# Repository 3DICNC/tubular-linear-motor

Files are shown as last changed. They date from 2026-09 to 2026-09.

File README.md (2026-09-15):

# Tubular linear motor

This repository documents an experimental moving-coil tubular motor for a 3D printer. The **active build** is the nine-coil prototype below. Rev62 and Rev64 assets are preserved as recovered historical material; they are not current drawings, calculations, winding instructions, or simulation results.

> **Build status — not qualified.** The active geometry has not yet passed a physical coil, force, thermal, encoder-field, or long-stroke test. The old Rev64 GIF and Elmer images are archived because their coil geometry and/or field representation are wrong. Do not use them to make engineering decisions.

Current nine-coil motor layout — schematic only

## Active prototype — one X-axis rail

| Feature | Current definition |
|---|---|
| Usable coil-centre travel | 370 mm |
| Magnet rod | 39 sections, 466 mm active stack |
| Each section | Two Ø10 × 5 mm axially magnetised N42SH discs, joined N-to-S |
| Spacer | Ø10 × Ø8 × 2 mm low-carbon-steel washer between sections |
| Section pitch | 12 mm |
| Tube | Carbon fibre Ø12 OD × Ø11 ID; buy 500 mm and trim after retention proof |
| Moving coil pack | **9 independent air coils**, 69 mm overall length |
| Each coil | 13 mm bore × 5 mm width, 120 turns AWG25 |
| Wire | 0.455 mm bare / about 0.496 mm finished; prepare 7.5 m per coil |
| Phase order | A–B–C–A–B–C–A–B–C; three series coils per phase |
| Controller | One MKS XDrive 3.6 channel at 48 V; braking resistor required |
| Feedback | RLS RLC2HD / MS05, mounted on the rail side away from the motor field |

The schematic shows intended physical arrangement only. It is not a field plot, animation, force prediction, wiring diagram, or manufacturing drawing.

## Current build documents

1. [Current prototype definition](docs/11-current-build.md) — mechanical, coil, thermal and encoder decisions.
2. [One-rail BOM](docs/12-one-rail-bom.md) — purchase/build list for the 370 mm X rail.
3. [Current winding recipe](winding-machine/docs/CURRENT_120T_AWG25_RECIPE.md) — setup and trial measurements.
4. [Current build records](records/README.md) — winding, force, thermal and release records.
5. [Project audit and withdrawn simulations](docs/13-project-audit.md) — what is historical and why.

## Historical recovered material

- [Rev62/Rev64 history](docs/02-history.md), preserved for provenance.
- [Archived CAD](cad/) and [archived FEMM work](simulation/rev64/), which do **not** match the active nine-coil rail.
- [Legacy manual](docs/ENGINEERING_MANUAL.md), which is a frozen Rev64 reference only.
- [Archived visual material](media/README.md), which must not be treated as a simulation.

## Recalculate and check the archived Rev64 references

These commands validate the recovered historical files only; they do not validate the active prototype:

```sh
python tools/calculate.py
python tools/verify.py
python -m unittest discover -s tests -v
```

## Repository layout

```text
bom/                     Current one-rail BOM plus preserved Rev64 BOM
cad/, simulation/rev64/  Historical recovered files; not the active design
concepts/                Exploratory work; check its status before reuse
docs/11-current-build.md Active mechanical/electrical definition
docs/12-one-rail-bom.md  Active X-rail procurement/build list
media/                   Current schematic and withdrawn legacy visuals
records/                 Current prototype test templates
winding-machine/         Winder hardware plus active winding recipe
tools/, tests/           Archived Rev64 reproducibility tools
```

No license has been selected. Keep the project private until ownership and release choices are settled.

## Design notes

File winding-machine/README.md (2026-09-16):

# Automatic coil winder — active build

This folder holds the hardware work for the coil winder. The **active plan** is a two-stepper machine for the current tubular-motor coils:

- one NEMA17 and driver turn the removable winding mandrel;
- one NEMA17 and driver move the wire guide on the **2 mm-pitch threaded rod**;
- the MKS controller and existing software provide spindle speed, turn count and guide synchronisation;
- no servo, belt reduction, bevel gear, mechanical reversing gear or electrical control design is required for this build.

## What the winder must produce

The target is one independent air coil with a 13 mm bore, 5 mm axial winding width, 120 turns of AWG25 copper (0.455 mm bare, about 0.496 mm finished). The motor uses nine matched coils per rail.

Use [the active winding recipe](docs/CURRENT_120T_AWG25_RECIPE.md) and [the trial record](../records/winding-trial.md). Wind one slow test coil first; its measured dimensions determine the final guide pitch and the design of the motor coil carrier.

## Hardware still required

1. Rigid base, spindle bearings, 13 mm removable mandrel and a simple non-magnetic end stop.
2. Wire-guide carriage driven by the 2 mm-pitch rod, with adjustable tensioner and smooth ceramic/metal eyelet.
3. Two NEMA17 motors, drivers and MKS control board already available to you.
4. Guard around rotating components, accessible emergency stop and a wire-break stop before normal operation.

## Historical files

The `rev_b_gt2`, `rev_c_printed_gears`, older CAD, old BOM and mechanical-reduction documents are retained as concept history. Their original Rev64 coil assumptions were 80 turns of 0.250 mm wire and must not be used for the active winding recipe. `legacy_rev64_winding_parameters.json` preserves those old values.

No current STEP manufacturing assembly is released yet because the spindle/mandrel dimensions need the first physical 13 mm coil trial. The existing hardware concepts can be adapted after that measurement.

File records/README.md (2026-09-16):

# Current prototype build records

These records apply to the active nine-coil prototype. Use the current 120-turn AWG25 definition, not the older Rev64 templates or archived simulation gradients.

- [Winding trial](winding-trial.md)
- [Static force test](force-test.md)
- [Thermal test](thermal-test.md)
- [Prototype release](release.md)

The historical Excel workbook remains in the archive for provenance. It is not an active specification.

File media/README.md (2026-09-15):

# Current nine-coil layout

`current-nine-coil-layout.svg` is a dimensional **schematic**, not a finite-element field plot or an animation. It depicts the active 39-section, 466 mm magnet rod, 12 mm pitch, nine 5 mm coils at 8 mm centres and the rail-side RLS encoder.

## Withdrawn visual material

- `rev64_real_life_motion.gif` and `rev64_animation_preview.png` show the recovered Rev64 six-coil concept at a 40 mm stroke. They are historical visuals only and do not represent the current motor.
- `elmer_coil_motion_study.gif` and its rendered frames are withdrawn from engineering use. The Elmer geometry did not represent the annular coil pack or its field correctly.

These files remain in the repository for traceability. Do not use them to estimate force, flux, movement, fit, or thermal behaviour.

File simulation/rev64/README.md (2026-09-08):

# Rev64 FEMM — 0.50 mm bobbin wall

`Rev64_CENTERED_0p5mm_BOBBIN_80T.fem` is the updated centred model. The complete six-coil geometry remains group 100, with winding radius 6.7 to 8.4 mm, four-millimetre width, centres -20, -12, -4, 4, 12 and 20 mm, phase order A-B-C-A-B-C and 80 turns per coil. Stationary nodes, segments and labels are unchanged from Rev62. The nonmagnetic bobbin is represented by the default air material, as in Rev62.

`Rev64_sweep_and_validate.lua` runs the 161-position PM flux-linkage sweep and then performs positive/negative direct-force checks at -20, 0 and +20 mm. It starts from an already-centred FEM file, so it does not apply the old -36 mm centring translation.

The average Rev64 unit-vector force constant is 2.375722 N/A, ranging from 2.351048 to 2.412174 N/A. Rev62 averaged 2.485202 N/A, so moving the windings outward for the thicker bobbin reduces the average by 4.405%. For sinusoidal phase peak scaling, multiply by sqrt(3/2): the Rev64 range is approximately 2.879 to 2.954 N/A phase peak, averaging 2.910 N/A phase peak.

The direct PM-odd force results agree with the derivative prediction within 0.35% at the three validation positions. The largest even-force residual is 0.000059 N. These values describe the existing first-pass static FEMM material model and do not include temperature, magnetic saturation curves, PWM or carbon-tube eddy-current effects.

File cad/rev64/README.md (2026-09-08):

# Rev64 CAD — 0.50 mm bobbin wall

The assembly is centred at Z=0 and uses millimetres. Open `Rev64_centered_assembly.step` for the complete 31-solid assembly. The magnet/steel stack, carbon tube and axial coil positions are unchanged from Rev62. The bobbin base OD is now 13.4 mm (12.4 mm ID plus two 0.5 mm walls), so each winding envelope is ID 13.4 mm, OD 16.8 mm and 4 mm wide.

`Rev64_parametric_model.scad` is editable and has a `position` control from -20 to +20 mm. All STEP exports were reopened and passed solid-validity, solid-count and volume checks. There are no positive-volume component intersections. At both travel limits the coil windings retain 5 mm axial margin within the 94 mm magnet stack; the 45 mm provisional bobbin retains 4.5 mm.

The five 4 mm separator lands and two 0.5 mm end flanges remain proposed mechanical features. Lead exits, crossover channels, adhesive allowance, mounting and manufacturing tolerances still require detailing.

The usable winding window is 4.0 mm axial by 1.7 mm radial. The proposed 80-turn trial winding uses six layers: 14 + 14 + 13 + 13 + 13 + 13. Specify 0.250 mm bare copper with Grade 1 enamel and a guaranteed finished diameter no greater than 0.281 mm. That published maximum gives 1.686 mm radial build and 3.934 mm maximum axial occupation in an ideal ordered winding. It leaves only 0.014 mm radial and 0.066 mm axial nominal allowance, so the actual wire certificate and a trial winding are required. AWG30 heavy-build wire does not fit this window, and generic “AWG30” is not a sufficient purchase specification.

The copper parts are homogenized winding envelopes rather than individual wires. The separate unassigned outer-envelope STEP preserves FEMM reference geometry and is excluded from the physical assembly.

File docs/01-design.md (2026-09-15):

# Design and coordinate system

> **Historical Rev64 reference — not the active build.** This file describes the recovered six-coil / 80-turn Rev64 concept. It does not define the current nine-coil prototype. Use [the current prototype definition](11-current-build.md), [one-rail BOM](12-one-rail-bom.md), and [project audit](13-project-audit.md) for active work.

## Architecture

The permanent-magnet/steel stack and carbon tube are stationary. Six wound coils and their common nonmagnetic bobbin move along Z. FEMM uses an axisymmetric cross-section with horizontal coordinate r and vertical coordinate z; the CAD axis is Z. All geometry files use millimetres. Force derivatives convert displacement to metres.

The carbon tube separates the magnet stack from the bobbin bore. A bore clearance is not a designed bearing: radial guidance, concentricity and lateral load capacity remain unspecified.

```mermaid
flowchart LR
  Drive[Three-phase current drive] --> Coils[Six coils on moving bobbin]
  Encoder[Position sensor: selection open] --> Drive
  Stack[Fixed alternating magnet pairs and steel rings] --> Field[Radial field through coil region]
  Field --> Force[Axial force]
  Coils --> Force
  Force --> Carriage[Carriage and guidance: design open]
```

## Parts and datums

| Item | Geometry / position |
|---|---|
| Magnet pairs | Eight 10 mm sections; each made from two Ø10 × 5 mm discs |
| Pair centres | Z = −42, −30, −18, −6, 6, 18, 30, 42 mm |
| Magnetization | First pair +Z, then −Z, +Z, −Z, +Z, −Z, +Z, −Z |
| Pole rings | Ø10 outside, Ø5 bore, 2 mm thick, centres −36, −24, −12, 0, 12, 24, 36 mm |
| Stack and tube ends | Z = −47 and +47 mm |
| Coil centres | Z = −20, −12, −4, 4, 12, 20 mm at displacement zero |
| Bobbin ends | Z = −22.5 and +22.5 mm at displacement zero |
| Coil pack ends | Z = −22 and +22 mm at displacement zero |

Both discs in each pair have the same axial magnetization. The CAD treats their interface as zero thickness. Adhesive or actual gaps must be added to the stack tolerance and electromagnetic models if used. Magnetization direction is a vector; an N/S marking procedure must be established and verified with a known pole reference before assembly.

The nominal assembly has 31 solids: 16 magnets + 7 steel rings + 1 tube + 6 winding envelopes + 1 bobbin. The winding envelopes occupy the allowable winding volume, not the actual copper fill. Their volume cannot be multiplied by copper density to obtain actual winding mass.

## Geometric travel

At either ±20 mm extreme, the farthest winding edge is 42 mm from the stack centre, leaving 5 mm to the stack end. The bobbin edge reaches 42.5 mm, leaving 4.5 mm. These are axial overlap margins only. The original commissioning notes proposed initial ±18 mm soft limits; these remain a proposed commissioning setting pending end-stop and encoder design.

## Reference envelope

The Ø17 bore / Ø23 outside annulus is unassigned FEMM reference geometry and is excluded from the physical STEP assembly. No steel yoke or centre through-rod is established by the source model. Introducing either requires a fresh electromagnetic and mechanical evaluation.

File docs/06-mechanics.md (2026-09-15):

# Mechanical assembly and tolerances

> **Historical Rev64 reference — not the active build.** This file describes the recovered six-coil / 80-turn Rev64 concept. It does not define the current nine-coil prototype. Use [the current prototype definition](11-current-build.md), [one-rail BOM](12-one-rail-bom.md), and [project audit](13-project-audit.md) for active work.

## Nominal geometry is not a shop drawing

The CAD includes five full-width 4 mm separator lands and two 0.5 mm end flanges. These were provisional additions in Rev62 and remain provisional in Rev64. Bobbin material candidates PEEK or G10 appear in the old workbook; neither is a selected, qualified process for this geometry.

Define manufacturing tolerances on the actual drawing before ordering final custom parts. In particular, Ø12.4 bore and Ø12 tube give only 0.20 mm nominal radial clearance. Tube straightness, ovality, bobbin shrinkage, guidance alignment and temperature expansion all contribute to minimum running clearance.

For measured worst-case diameters, radial clearance c_min = (bobbin_ID_min − tube_OD_max)/2 − eccentricity_allowance. Similar stack-to-tube clearance is (tube_ID_min − magnet_OD_max)/2 before coating and assembly allowances. A numerical tolerance budget requires those actual limits.

The nominal winding OD allowance relative to the reference bore is only (17 − 16.8)/2 = 0.10 mm, but no physical reference housing is selected. Do not use this as a verified bearing fit.

## Assembly sequence to develop

1. Inspect magnet dimensions, axial magnetization and pole-ring geometry. Confirm pole material and magnet supplier certificate. Use a suitable fixture for the interacting magnets; the alternating stack contains repelling interfaces and needs defined retention.
2. Define adhesive gaps and end retention, then calculate the assembled stack length and revise CAD/FEMM if the nominal 94 mm changes.
3. Trial the fixed stack inside the measured carbon tube without damaging coatings. Do not treat the Ø5 pole-ring holes as a continuous bore through the solid magnets.
4. Complete the single-pocket winding trial and winding inspection before committing to the six-pocket former.
5. Add coil crossover routes, lead exits and strain relief while preserving the required radial envelope. Record any geometry change as a new revision.
6. Design carriage attachment, guides, end stops and encoder datum together. The winding pack must not carry unspecified lateral loads through rubbing contact with the tube.
7. Confirm free travel and measured margins with the assembled lead harness before electrical commissioning.

This is a development sequence. Detailed retention, guidance and connection drawings remain required for assembly release.

## Material and environment requirements

Record bobbin modulus, creep behaviour and temperature limit; adhesive cure shrinkage and temperature range; tube thermal expansion, straightness and conductivity; magnet temperature-dependent properties and coating. The minimum compatible limit of the insulation/material system constrains operation. Carbon composite properties depend on layup, so a generic isotropic assumption does not establish thermal or mechanical performance.

Mass, stiffness, buckling, bearing life and fatigue calculations are pending the carriage, support spans, material properties, load directions and duty cycle. Do not substitute the 0.5 kg historical carriage target for a measured moving assembly mass.

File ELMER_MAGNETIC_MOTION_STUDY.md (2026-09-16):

# Elmer magnetic-motion study — withdrawn

**Status: withdrawn from engineering use.** The published Elmer images, GIF and related exploratory inputs did not model the coil and magnetic geometry correctly for the active nine-coil motor. They are retained for traceability only and do not support force, flux, heating or motion conclusions.

The active dimensions are in [docs/11-current-build.md](docs/11-current-build.md). The audit and requirements for a replacement correlated model are in [docs/13-project-audit.md](docs/13-project-audit.md).

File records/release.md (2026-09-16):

# Prototype release record

Build ID: ___   Revision: Current nine-coil prototype   Reviewer/date: ___

| Requirement | Evidence | Disposition |
|---|---|---|
| Active dimensions and orientation confirmed | | Pending |
| 120-turn AWG25 trial-coil fit after cure | | Pending |
| Nine coils: turns, resistance, insulation | | Pending |
| Phase topology A-B-C-A-B-C-A-B-C and polarity | | Pending |
| Magnet retention, spacer and tube assembly | | Pending |
| Guidance, carriage, stops and leads | | Pending |
| Encoder datum, field and travel | | Pending |
| Force map from physical restrained test | | Pending |
| Thermal test in 70 C environment | | Pending |
| Continuous and peak ratings with conditions | | Pending |
| Deviations and manufacturing drawings | | Pending |

Overall release: Pending

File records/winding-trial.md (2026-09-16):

# Winding trial record

Build ID: ___   Revision: Current nine-coil prototype   Date: ___   Operator: ___

Wire supplier/lot/certificate: ___
Enamel type/thermal class: ___
Instrument and calibration: ___
Former material/release process: ___

| Measurement | Nominal / plan | Actual |
|---|---:|---|
| Bare wire diameter, mm | 0.455 | |
| Finished wire diameter, mm | about 0.496 | |
| Former / coil bore, mm | 13.0 | |
| Winding width, mm | 5.0 | |
| Total turns | 120 | |
| Coil64 reported layers | 14 estimate; verify physically | |
| Final winding OD, mm | about 26; verify physically | |
| Final axial occupation, mm | 5.0; verify physically | |
| Prepared wire length, m | 7.5 | |
| Actual total wire length, m | Record including leads | |
| Coil resistance, Ω | about 0.752 at 20 C; verify | |
| Reference temperature, °C | Measured | |
| Copper mass, g | about 10.326 excluding leads; verify | |
| Insulation test method/result | Defined for selected system | |

Start/finish identification and viewing direction: ___
Crossover and lead-route photo/drawing: ___
Guide pitch, tension and spindle speed: ___
EL160 cure and post-cure dimensions: ___
Observed enamel damage or fit issues: ___
Disposition and evidence: Pending

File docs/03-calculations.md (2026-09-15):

# Calculations and assumptions

> **Historical Rev64 reference — not the active build.** This file describes the recovered six-coil / 80-turn Rev64 concept. It does not define the current nine-coil prototype. Use [the current prototype definition](11-current-build.md), [one-rail BOM](12-one-rail-bom.md), and [project audit](13-project-audit.md) for active work.

Run `python tools/calculate.py` from the repository root to generate [results](../calculations/results.md) and [machine-readable values](../calculations/results.json). Inputs are in [parameters.json](../calculations/parameters.json). The calculator rejects impossible layer counts and gross overfill; passing those checks does not prove a manufacturable winding.

## Source hierarchy and units

Geometry comes from Rev64 CAD parameters and FEMM coordinates. Force comes from archived simulation CSVs. Wire dimensions and resistance per metre come from the linked Elektrisola IEC table. Extra lead length, procurement allowance, copper density and temperature coefficient are explicitly stated estimates. The historical mass and acceleration are workbook targets, not newly confirmed requirements. SI units are used for electromagnetic and dynamic equations; geometry uses mm with explicit conversions.

## Geometry

Let N_c be coil count, p coil pitch, w coil width, t bobbin wall and D_b bobbin bore.

- Stack length = 16 × 5 + 7 × 2 = 94 mm.
- Coil-pack length = (N_c − 1)p + w = 44 mm.
- Bobbin length = 44 + 2 × 0.5 = 45 mm.
- Coil ID = D_b + 2t = 13.4 mm.
- Radial window h = (16.8 − 13.4)/2 = 1.7 mm.
- Window cross-section = wh = 6.8 mm².
- Minimum winding end margin = 94/2 − 20 − 44/2 = 5 mm.
- Minimum bobbin end margin = 94/2 − 20 − 45/2 = 4.5 mm.
- Magnet-to-tube radial gap = (10.2 − 10)/2 = 0.10 mm.
- Tube-to-bobbin radial gap = (12.4 − 12)/2 = 0.20 mm.

For an annular component, V = π(D_o² − D_i²)L/4. Use D_i = 0 for a solid magnet disc. Bobbin volume equals the base sleeve plus the radial material above the base over the five 4 mm lands and two 0.5 mm flanges. Source component volumes are independently checked against these formulas.

## Winding fit

At finished wire diameter d_f = 0.281 mm, the ordered rectangular plan is 14 + 14 + 13 + 13 + 13 + 13 = 80 turns. Six layers occupy 6d_f = 1.686 mm radially. The widest layer occupies 14d_f = 3.934 mm axially. Nominal allowances are 0.014 mm radially and 0.066 mm axially.

The purely geometric diameter ceiling is min(1.7/6, 4/14) = 0.283333 mm, before any allowance. The specified 0.281 mm maximum is below that ceiling but only barely. Real crossovers, irregular stacking, enamel variation, bobbin tolerance and impregnation consume clearance. No extra insulation or adhesive allowance is built into the nominal fit.

Bare copper area A = πd_bare²/4 = 0.0490874 mm². Cross-sectional copper fill fraction = 80A/(4 × 1.7) ≈ 57.75%. This area fraction does not describe packing difficulty by itself. It also is not exactly the winding-volume fill when the turn counts vary by layer radius.

## Wire length, resistance and mass

For layer j starting at zero, centre diameter D_j = D_coil_ID + (2j + 1)d_f. Approximate turn length is πD_j. The model uses L_winding = Σ(n_j πD_j)/1000 metres. It neglects the tiny helical correction and excludes crossovers and terminals.

The explicit allowance is 0.20 m extra wire per coil. This is a planning input, not a recovered lead-routing dimension. Total wire per coil = L_winding + allowance. Production consumption is six times that value. A separate 20% procurement allowance is applied only to purchase length, not electrical resistance or copper mass. One trial coil adds its own consumption before that allowance.

R_coil,20 = wire length × 0.3482 Ω/m. The supplier table's 0.3345–0.3628 Ω/m range produces an estimated resistance band for the same length. Each series phase has two coils, so R_phase = 2R_coil, plus any extra interconnect resistance not included in the allowance. For a balanced star connection measured between two terminals with the third open, R_line-line = 2R_phase. These relations do not apply unchanged to delta wiring.

Copper mass = A × length × density after unit conversion. Density 8.9 g/cm³ is an estimate. Insulation, solder, lead dress, bobbin, carriage and adhesive are excluded. Bobbin CAD volume is available, but bobbin mass remains V × selected-material density. Total moving mass is unavailable until the mechanical BOM is specified.

## Force and current definitions

For phase permanent-magnet flux linkages λ_A, λ_B, λ_C in Wb-turn and displacement x in metres, define g = dλ/dx. Remove the common-mode component: p = g − mean(g)[1,1,1]. Then K = ||p||₂ and u = p/K. The optimum balanced current is i = I_vector u, satisfying sum(i) = 0 and ||i||₂ = I_vector. Its PM force prediction is F = g·i = K I_vector.

The archived script uses centred differences at interior samples and one-sided differences at ±20 mm. Displacement spacing is 0.25 mm. These gradients and normalized currents are checked again from the saved flux data.

For the conventional balanced sinusoidal scaling, I_vector = sqrt(3/2) I_phase_peak, and each phase RMS over a sinusoidal cycle is I_phase_peak/sqrt(2). Therefore K_phase_peak_equivalent = sqrt(3/2) K. The saved optimum vectors are not a guarantee that an arbitrary fixed sinusoidal commutation law produces the same force. At standstill, the individual DC phase values differ from their over-cycle RMS values. Always state which current convention is used.

Direct-force validation uses F_PM_odd = [F(+i) − F(−i)]/2 and F_even = [F(+i) + F(−i)]/2. Relative difference = 100(F_PM_odd − K)/K for the saved unit-vector currents. Three checks are consistency evidence, not a full mesh-convergence study or measured force map.

## Copper loss and temperature

For equal phase resistance R_phase and arbitrary instantaneous currents, P_copper = R_phase(i_A² + i_B² + i_C²) = R_phase I_vector². Under equivalent sinusoidal phase-peak scaling this becomes 1.5 R_phase I_phase_peak². Current scenarios in the generated table are arithmetic examples, not approved operating limits.

R(T) = R20[1 + α(T − 20°C)], using α = 0.00393/K as an estimate. A measured reference at T_ref gives T = 20 + {(R/R_ref)[1 + α(T_ref − 20)] − 1}/α. Measure after settling and account for lead/contact resistance. This estimates average copper temperature, not the hottest turn.

At thermal steady state, Rθ ≈ (T − T_ambient)/P. With equal phase resistances, a provisional current calculation would be I_phase_peak ≤ sqrt[(T_limit − T_ambient)/(1.5 R_phase(T_limit) Rθ)]. Rθ, ambient worst case, material-compatible T_limit and duty cycle are missing, so no continuous-current result is assigned. The old 120°C workbook entry is not an approved limit.

## Load, acceleration and orientation

Historical targets give F_inertia = ma = 0.5 × 5.186 = 2.593 N. A vertical upward acceleration requires F = m(a + g) + friction + external load; with gravity alone added, F = 7.496325 N. Horizontal force ignores gravity along the axis but still needs friction and cable load. The generated estimates divide these loads by the minimum archived K to show conservative position-based current within this first-pass simulation. They do not include a design margin or magnetic-temperature derating.

Holding force on a vertical axis is mg even at zero acceleration. A commanded current failure cannot be treated as a holding brake. Orientation must be confirmed before accepting an operating envelope.

## Back EMF, voltage and missing dynamic calculations

For each phase, e_j = (dλ_j/dx)v. The relevant line voltage is e_A − e_B, etc. The generated results report the largest absolute saved phase and line gradient, which give voltage per m/s. Multiplying the projected force constant by velocity does not automatically give a phase-to-phase back-EMF value.

General phase voltage is v = Ri + d(Li)/dt + e_PM, with mutual terms in the inductance matrix and position dependence if present. A first current-ramp estimate is di/dt ≈ (V_available − Ri − e)/L only after defining the electrical circuit and inductance. The 12 mm adjacent-pair pitch implies a nominal 24 mm magnetic period, so f_e ≈ |velocity|/0.024 m away from end effects. Full force commutation should use a calibrated position/phase map.

Inductance matrix, bus voltage, maximum speed, PWM ripple, eddy losses, saturation, magnetic temperature effects, fatigue life, structural deflection and a thermal duty rating cannot be calculated numerically from the supplied evidence. Required inputs and tests are listed in the roadmap; no guessed values are presented as results.

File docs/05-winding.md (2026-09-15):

# Winding and electrical connections

> **Historical Rev64 reference — not the active build.** This file describes the recovered six-coil / 80-turn Rev64 concept. It does not define the current nine-coil prototype. Use [the current prototype definition](11-current-build.md), [one-rail BOM](12-one-rail-bom.md), and [project audit](13-project-audit.md) for active work.

## First-coil wire specification

Request solid enamelled copper magnet wire with 0.250 mm nominal bare conductor, Grade 1 insulation and a supplier-guaranteed finished diameter ≤0.281 mm. Ask for the insulation chemistry, thermal class, resistance per metre, batch certificate and handling/termination guidance. Thermal class and enamel grade are different specifications. Final thermal class must be compatible with the selected bobbin, adhesive and temperature envelope.

The manufacturer's IEC table lists Grade 1 finished diameter 0.267–0.281 mm and nominal resistance 0.3482 Ω/m for 0.250 mm copper. [Elektrisola diameter/resistance table](https://www.elektrisola.com/Attachments/TechnicalDataBySize/ELEKTRISOLA_EnCuWire_IECJIS_Datasheet_eng.pdf).

Generic AWG30, Grade 2 or self-bonding wire must not be accepted by name alone. Additional coatings count toward finished diameter. A 20–25 m trial spool permits several winding attempts, but it is not the calculated procurement quantity for all six production coils plus a trial.

## Single-pocket trial

1. Identify the bobbin process/material and measure the actual bore, base diameter and pocket width. Design a smooth lead exit and crossover route before winding. The original CAD does not contain those routes.
2. Record wire supplier and lot. Check finished diameter at multiple positions using suitable low-force measurement. Keep the supplier's maximum specification as the procurement requirement.
3. Label start and finish leads. Define and photograph the winding direction from a stated viewing end; do not rely on an ambiguous clockwise instruction.
4. Trial the six-layer plan, counting 14, 14, 13, 13, 13, 13 turns from inner to outer layers. Record actual build after each layer. Use supplier-compatible tension and avoid damaging enamel at flange edges.
5. Record final OD, width, turn count and resistance at a measured temperature. Compare against the calculation with actual lead length.
6. Inspect insulation integrity and lead strain relief before impregnation. Select an insulation test method/voltage compatible with the actual insulation system and equipment; none is prescribed by the recovered design.
7. Confirm fit after the intended impregnation/cure process. Use the trial record to release or redesign the pocket. Do not force an oversized winding into the envelope.

## Phase mapping

| Coil | Centre at zero, mm | Phase | Proposed pair |
|---|---:|---|---|
| C1 | −20 | A | C1 + C4 in series |
| C2 | −12 | B | C2 + C5 in series |
| C3 | −4 | C | C3 + C6 in series |
| C4 | 4 | A | C1 + C4 in series |
| C5 | 12 | B | C2 + C5 in series |
| C6 | 20 | C | C3 + C6 in series |

Each FEMM label has +80 turns. A matched physical winding direction and additive series connection must reproduce that sign convention. Confirm induced-voltage polarity or restrained low-current force direction before making final series joints. A model's positive turns do not identify physical start/finish terminals by themselves.

```mermaid
flowchart LR
  A[Phase A terminal] --> C1[Coil 1] --> C4[Coil 4] --> N[Candidate star point]
  B[Phase B terminal] --> C2[Coil 2] --> C5[Coil 5] --> N
  C[Phase C terminal] --> C3[Coil 3] --> C6[Coil 6] --> N
```

This is a proposed star topology for planning, not a recovered terminal drawing. Controller compatibility, neutral treatment and verified series polarity are required before wiring release. Keep individual coil leads accessible during the trial stage. All current and resistance calculations state their topology explicitly.

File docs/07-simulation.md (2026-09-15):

# Simulation and reproduction

> **Historical Rev64 reference — not the active build.** This file describes the recovered six-coil / 80-turn Rev64 concept. It does not define the current nine-coil prototype. Use [the current prototype definition](11-current-build.md), [one-rail BOM](12-one-rail-bom.md), and [project audit](13-project-audit.md) for active work.

## Archived model

The preserved Rev64 FEMM file is a static axisymmetric model in millimetres with precision 1e−8, a zero-vector-potential outer boundary and an approximately r = 0–30 mm, z = −60–60 mm air domain. All six coils are group 100. Their radii are 6.7–8.4 mm and their centres are −20, −12, −4, 4, 12, 20 mm. The saved starting phase currents are −1, +0.5, +0.5 A; the sweep resets them to zero.

| Material | Saved model assumption |
|---|---|
| Air and implicit bobbin | Relative permeability 1 |
| CarbonTube | Relative permeability 1, conductivity 0 |
| Steel_firstpass | Constant relative permeability 1000, no B–H points |
| N42SH_firstpass | Relative permeability 1.05, coercive field 1,000,000 A/m |
| Copper | Conductivity 58 MS/m; no explicit individual-wire geometry |

The magnetic material label is not a verified supplier material curve. The model omits thermal feedback, real steel saturation, magnet temperature dependence, PWM and conductive carbon-tube losses. Treat winding resistance from physical wire geometry and measurements separately from a homogenized coil-region solution.

## What the archived sweep does

It translates the whole coil group through 161 positions at 0.25 mm increments over ±20 mm, extracts zero-current PM circuit flux linkages, differentiates them and calculates balanced optimum current vectors. It then solves positive and negative currents at −20, 0 and +20 mm and integrates axial Lorentz force on all six coil regions.

FEMM `mo_blockintegral(12)` is the steady-state axial Lorentz-force component for an axisymmetric magnetic model. The official [FEMM manual](https://www.femm.info/Archives/doc/manual.pdf) documents the integral and circuit-property APIs. The air-like coil permeability makes this force calculation appropriate for the coil regions.

The saved direct-force comparisons are within 0.35%; the largest even component is about 0.000059 N. Recalculation of saved data is not a new finite-element solve. Archived CAD-kernel reimport checks are also preserved evidence, not rerun by the documentation tools.

## Fresh runs without overwriting the archive

The preserved Lua uses absolute paths from its original computer location. Do not run it in place. Instead:

```sh
python tools/prepare_femm.py --output work/femm-trial-01
```

The tool creates a new directory, copies the centred model, adapts only the input/output paths in a copied Lua script, and removes automatic application exit. It refuses an existing output directory. Open FEMM and use its Lua script command to select the generated script. The script creates new CSVs inside the run directory. The original simulation directory stays untouched.

Do not apply the older −36 mm translation to this already-centred model. Wait for the run's `progress.txt` to report completion. Archive the new model, outputs, solver version and machine/run notes together. The run preparation tool has been checked for file isolation; the resulting Lua has not been executed as part of this documentation task.

## Before treating force as a release value

Perform mesh refinement and air-boundary sensitivity studies, compare central and endpoint differentiation schemes, add supplier magnetic curves and temperature cases, check proposed metal fixtures, measure force at known phase currents and positions, and resolve the actual drive's commutation law. Losses and dynamics require additional models and measurements. Model convergence at a numerical precision setting alone does not establish physical accuracy.

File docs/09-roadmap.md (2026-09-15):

# Open decisions and milestones

> **Historical Rev64 reference — not the active build.** This file describes the recovered six-coil / 80-turn Rev64 concept. It does not define the current nine-coil prototype. Use [the current prototype definition](11-current-build.md), [one-rail BOM](12-one-rail-bom.md), and [project audit](13-project-audit.md) for active work.

| ID | Decision / work | Required evidence | Status |
|---|---|---|---|
| M1 | Confirm axis orientation, moving mass, acceleration and stroke | Updated requirements including gravity, friction and cable forces | Open |
| M2 | Qualify wire and single-pocket winding | Supplier certificate and measured 80-turn sample after cure | Open |
| M3 | Detail bobbin and crossover channels | Material/process choice, tolerance drawing and lead routing | Open |
| M4 | Detail magnet retention and tube installation | Adhesive gaps, fixture, end retention and tolerance stack | Open |
| M5 | Design guidance, carriage, stops and sensor mount | Assembly CAD, loads, stiffness and measured free travel | Open |
| M6 | Confirm electrical topology and polarity | Terminal drawing, individual coil/phase resistance and polarity record | Open |
| M7 | Improve and validate electromagnetics | Material curves, mesh/boundary study and calibrated force measurements | Open |
| M8 | Select driver, encoder and power supply | Inductance/back-EMF data, required speed, current convention and interface | Open |
| M9 | Establish thermal and duty limits | Stable tests in final mounting and worst ambient | Open |
| M10 | Release prototype build | Closed deviations, complete BOM and approved manufacturing drawings | Open |

Recommended order: requirements confirmation and wire procurement in parallel, then the single-pocket trial, mechanical detailing, full coil assembly, restrained electrical/force tests, and thermal qualification. Changing wire gauge, turn count, coil geometry or adding magnetic hardware requires re-evaluating force and electrical calculations.

## Change control

Keep recovered CAD and simulation files unchanged as baselines. Put design changes under a new revision directory. Describe changed dimensions, reason, source evidence and affected calculations. Generate fresh STEP exports, rerun relevant simulations and compare against baseline. Attach build/test evidence to the same revision. Do not promote an assumption to a measured fact without a record.

The GitHub issue template supports each milestone's requirements, evidence and acceptance criteria. This repository is the requested GitHub project; a separate GitHub Projects board is not assumed.

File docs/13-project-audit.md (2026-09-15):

# Project audit — current build versus recovered material

Audit date: 2026-09-15.

## Active engineering definition

The only active motor definition is [11-current-build.md](11-current-build.md), supported by the [one-rail BOM](12-one-rail-bom.md) and [current winding recipe](../winding-machine/docs/CURRENT_120T_AWG25_RECIPE.md): nine 120-turn AWG25 air coils on 8 mm centres; Ø10 × 5 mm N42SH discs paired into 10 mm sections; 2 mm steel spacers; 12 mm pitch; 12/11 mm carbon tube; 370 mm X coil-centre travel.

## Material retained as historical

The Rev62/Rev64 CAD, FEMM, calculations, manual, old BOM, visual GIF and winder parameters describe a different six-coil, 80-turn, 40 mm-stroke concept. They are retained for source recovery and comparison only. They must not be used as current manufacturing or electrical instructions.

## Withdrawn simulation claims

The prior Elmer motion study is withdrawn as a physical field/force model. Its coil geometry and rendered flux representation do not correctly model the active annular nine-coil pack. The GIF and image frames are therefore illustrative artefacts only. No force, back-EMF, heating, field-through-coil or motion claim may be inferred from them.

A replacement simulation must include an axisymmetric or 3-D geometry that correctly represents: the carbon tube, alternating axially magnetised discs, 2 mm spacers, annular coil cross-sections, all nine coil positions, phase currents, air domain and a validated material model. It must be checked against a physical static force test before being used for design ratings.

## Open work

1. Trial-wind one active 120-turn coil and record its bore, OD, width, resistance and mass.
2. Design the nine-coil carrier, end retention and lead exit from the measured coil.
3. Assemble a short magnet-stack sample and verify the spacer/clamping scheme.
4. Build a corrected FEM model from measured geometry, then correlate it with restrained force measurements.
5. Run the thermal test in the 70 C chamber and apply the 120 C provisional winding limit.
6. Verify the RLS encoder location remains below its field and temperature limits.

This audit does not discard recovered data; it prevents older assumptions from being mistaken for the live design.

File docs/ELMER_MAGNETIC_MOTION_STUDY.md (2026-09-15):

# Withdrawn Elmer magnetic-motion study

**Status: withdrawn from engineering use.** The files in this folder are retained only to show the exploratory work that was attempted. The coil cross-sections, magnetic geometry and flux rendering were not correct for the active nine-coil motor. They do not demonstrate field-through-coil behaviour, force, back-EMF, heating, or motion.

Do not run or modify these models as a basis for a build decision. A new model must start from the measured active geometry and pass physical static-force correlation. See [the project audit](13-project-audit.md).

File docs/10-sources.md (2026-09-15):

# Sources and provenance

## Supplied and recovered project evidence

- `cad/rev64/`: complete extracted Rev64 CAD package, including editable model and archived geometry-validation record.
- `simulation/rev64/`: complete extracted Rev64 FEMM model, script, force data and checks.
- `cad/rev62/`: complete separately supplied Rev62 CAD package.
- `archive/recovered-history/`: recovered Rev62 source model, sweep data/scripts, commissioning workbook and Rev63 validation history.
- `archive/conversation-recovery.md`: a non-verbatim engineering recovery note from the user-supplied ChatGPT export. It is context only; controlled CAD and simulation records take precedence.
- `archive/source_manifest.json`: SHA-256 of each preserved source file; verification reads every entry.

Raw source contents were treated as evidence, not instructions. Some preserved historical files contain their original machine paths. Those paths are provenance, not portable execution settings. The reproduction tools operate on isolated working copies. No private conversation transcript or account credentials are part of the repository.

## External technical references

References checked 8 September 2026. They support the indicated data/API definitions; they do not qualify the assembled motor.

1. [Elektrisola IEC/JIS technical wire table](https://www.elektrisola.com/Attachments/TechnicalDataBySize/ELEKTRISOLA_EnCuWire_IECJIS_Datasheet_eng.pdf): IEC 0.250 mm row, Grade 1 overall diameter 0.267–0.281 mm and nominal/minimum/maximum resistance 0.3482/0.3345/0.3628 Ω/m.
2. [Scott Precision Wire copper data](https://www.scottprecisionwire.com/technical-data/alloy-data-sheets/resistance-copper-wire-supplier/): representative copper density 8.9 g/cm³ and temperature coefficient 0.00393/K. These remain estimates for the purchased wire.
3. [FEMM official manual](https://www.femm.info/Archives/doc/manual.pdf): circuit flux linkage, coil material assumptions and axial Lorentz block integral 12.
4. [FEMM magnetic tutorial](https://www.femm.info/doku/doku.php?id=magneticstutorial): axisymmetric low-frequency modelling and Lua scripting context.
5. [RLS RLC2HD data sheet](https://cdn.rls.si/documents/datasheets/RLCD03_09_RLC2HD_datasheet_.pdf): preferred linear incremental encoder, 5 V TTL A/B/Z interface, magnetic-scale requirements, external-field limit and operating-temperature limit.
6. [RLS RLC2HD configurator](https://www.rls.si/eng/rlc2hd-miniature-linear-and-rotary-pcb-level-incremental-magnetic-encoder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): selected readhead configuration and the matching MS05 scale / cover-foil family.
7. [ODrive incremental encoder wiring](https://docs.odriverobotics.com/v/latest/manual/hardware-config.html): A/B/Z incremental encoder connection at 5 V.
8. [Easy Composites EL160](https://www.easycomposites.eu/el160-high-temperature-epoxy-laminating-resin): selected coil-impregnation resin and cure information.

Full third-party manuals and standards have not been copied into the repository. No supplier SKU, live stock, price or product compatibility has been invented. Quotations and procurement certificates remain to be obtained.

## Verification boundaries

New checks: archived data consistency, source hash matching, analytical dimensions/volumes, current normalization, finite-difference flux gradients, force statistics, direct-force decomposition, calculation edge cases and documentation links.

Not newly performed: FEMM solve, CAD-kernel solid reimport, physical winding, force or thermal test, native Excel recalculation. Archived records of prior numerical/CAD checks are retained as such.

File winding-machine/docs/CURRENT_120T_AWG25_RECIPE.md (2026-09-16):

# Current 120-turn AWG25 winding recipe

This is the **only** active coil-winding instruction. The CAD and documents elsewhere in `winding-machine/` were built around the earlier Rev64 80-turn, 0.250 mm wire coil and are retained as winder hardware references only. Do not use their 80-turn layer schedules.

## Trial coil specification

| Item | Value |
|---|---:|
| Coil count for one rail | 9 |
| Former / winding bore | 13.0 mm |
| Axial winding width | 5.0 mm |
| Turns | 120 |
| Copper | AWG25, 0.455 mm bare / about 0.496 mm finished |
| Prepared wire | 7.5 m per coil |
| Coil64 estimate | 238 µH, 0.752 Ω at 20 C, 7.088 m excluding leads, 10.326 g copper, reported 14 layers |
| Target finished geometry | 5 mm width × about 26 mm OD — measure; do not assume it fits until trialled |

## Winder setup

1. Use a removable 13.0 mm mandrel with release agent compatible with EL160. Keep the wire guide aligned with the middle of the 5 mm winding zone.
2. Set the spindle to 30 rpm for the first coil. Maintain only enough tension to lay the wire tightly without damaging enamel.
3. Use the 2 mm-pitch threaded rod guide. With a 200-step motor at 16 microsteps, the starting value is 1,600 guide steps/mm.
4. **Do not use an automatic 80-turn or fixed layer recipe.** The effective packing pitch depends on the actual coated diameter, tension and former. The Coil64 14-layer estimate is a geometry estimate, not a proven traverse program.
5. Wind one 120-turn sample, photograph every layer, and record its final bore, OD, width, resistance at measured temperature and wire length. Then tune the guide rate from that coil before producing the other eight.
6. Impregnate with EL160 according to the supplier cure/post-cure schedule. Measure again after cure before finalising the carrier CAD.

Use [the winding trial record](../../records/winding-trial.md) for each sample.

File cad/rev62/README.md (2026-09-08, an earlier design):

# Rev62 nominal CAD assembly

Open `Rev62_centered_assembly.step` in your CAD application. It contains 31 named solid components, in millimetres, with the motor axis along Z and the coil pack centred at Z=0. The STEP solids retain analytic cylindrical geometry; these are actual solid CAD files.

`Rev62_parametric_model.scad` is the editable OpenSCAD model. Change the parameters at its top or in the Customizer. Set `cutaway=true` for an axial half-section, select a component with `part`, or change `position` between -20 and +20 mm to move the complete winding pack and bobbin. Changes to dimensions require new electromagnetic and mechanical checks. The supplied STEP files are the nominal configuration and do not update automatically when the SCAD model is edited.

## Included components

| Component | Quantity | Nominal dimensions, mm |
|---|---:|---|
| Magnet discs | 16 | OD 10, axial length 5; paired into eight 10 mm sections |
| Steel pole rings | 7 | OD 10, ID 5, axial length 2 |
| Carbon tube | 1 | OD 12, ID 10.2, axial length 94 |
| Winding envelopes | 6 | OD 16.8, ID 12.6, axial length 4; 8 mm pitch |
| Provisional bobbin | 1 | ID 12.4, base OD 12.6, land/flange OD 16.8, overall length 45 |

Coils C1–C6 are ordered in increasing Z, at -20, -12, -4, 4, 12 and 20 mm; phases A–B–C–A–B–C, 80 turns each. Copper solids represent winding envelopes, not individual wires or solid-copper manufactured rings.

The magnetic stack and tube extend from Z=-47 to +47. Magnet pair centres are -42, -30, -18, -6, 6, 18, 30 and 42. The first pair is magnetized +Z, followed by alternating -Z/+Z pairs. Both 5 mm discs within one pair share the same magnetization. Pairing 10 mm FEMM sections into two physical 5 mm discs follows the earlier build specification; there is no adhesive thickness or gap between them in this nominal model.

## Source and interpretation

Geometry was checked against `E:/temp/Rev62_4mm_COILS_2.1mm_RADIAL_80T_ROBUST_BOBBIN.fem`. The source file still has coil centres 16 to 56 mm; the supplied CAD applies the sweep's -36 mm centring translation to the coils only. Its 24 coil nodes, 24 segments and six labels belong to group 100. Magnet labels are group 10; steel labels are group 20; the tube label is group 30. Physical bobbin geometry was not explicitly drawn in FEMM.

The pole regions have a boundary at radius 2.5 mm and a steel label outside that boundary. Their inner regions have no steel label and use the default air material: the matching CAD parts are rings, not full discs.

The FEMM annulus at radius 8.5–11.5 mm has no assigned block label. It therefore does not establish a physical steel yoke. Its separate `REFERENCE_ONLY.step` file preserves that geometry for inspection and is excluded from the physical assembly. The air domain is also excluded. Adding a steel housing here would change the electromagnetic model.

## Provisional mechanical details

The previous selected bobbin ID and 0.10 mm wall were retained. To make a complete solid former with six 4 mm winding pockets, this CAD adds five full-width 4 mm intercoil lands and two 0.5 mm end flanges. These dimensions are proposed here, not recovered from FEMM. The former uses nonmagnetic material in space treated as air by FEMM; final material selection, tolerances and fabrication method remain open. The thin wall is a nominal design value, not a demonstrated manufacturing capability.

Leads, winding crossover channels, insulation build, adhesive thickness, end retainers, bearings, carriage interfaces and external mounts are not yet defined. They require a subsequent mechanical detail revision before fabrication. No unspecified steel housing or central through-rod has been added.

## Verification

All nine STEP exports were reopened using the CAD kernel and checked for valid solid topology, expected solid counts and matching volumes. The main assembly contains 31 solids and has no positive-volume component intersections at the centred position. The analytical travel checks cover the entire continuous -20 to +20 mm interval because each coaxial moving component has a constant radial envelope. Minimum nominal radial gaps are 0.10 mm from magnets to tube and 0.20 mm from tube to bobbin. Coil OD is 0.10 mm radially inside the separate reference bore, if that bore is later used mechanically.

At both travel extremes, every coil remains inside the 94 mm magnetic stack, with a minimum axial margin of 5 mm. The 45 mm bobbin retains a minimum margin of 4.5 mm. These are geometry checks, not a bearing design or a tolerance analysis. `Rev62_geometry_validation.json` records dimensions, source fingerprint, component volumes, STEP reimport results and end-position checks. The PNG preview is a section rendering of the actual CAD solids.

Subassembly STEP files retain assembly coordinates. Reusable single magnet, pole ring and coil-envelope files have their lower face at Z=0. The isolated bobbin is centred at Z=0.

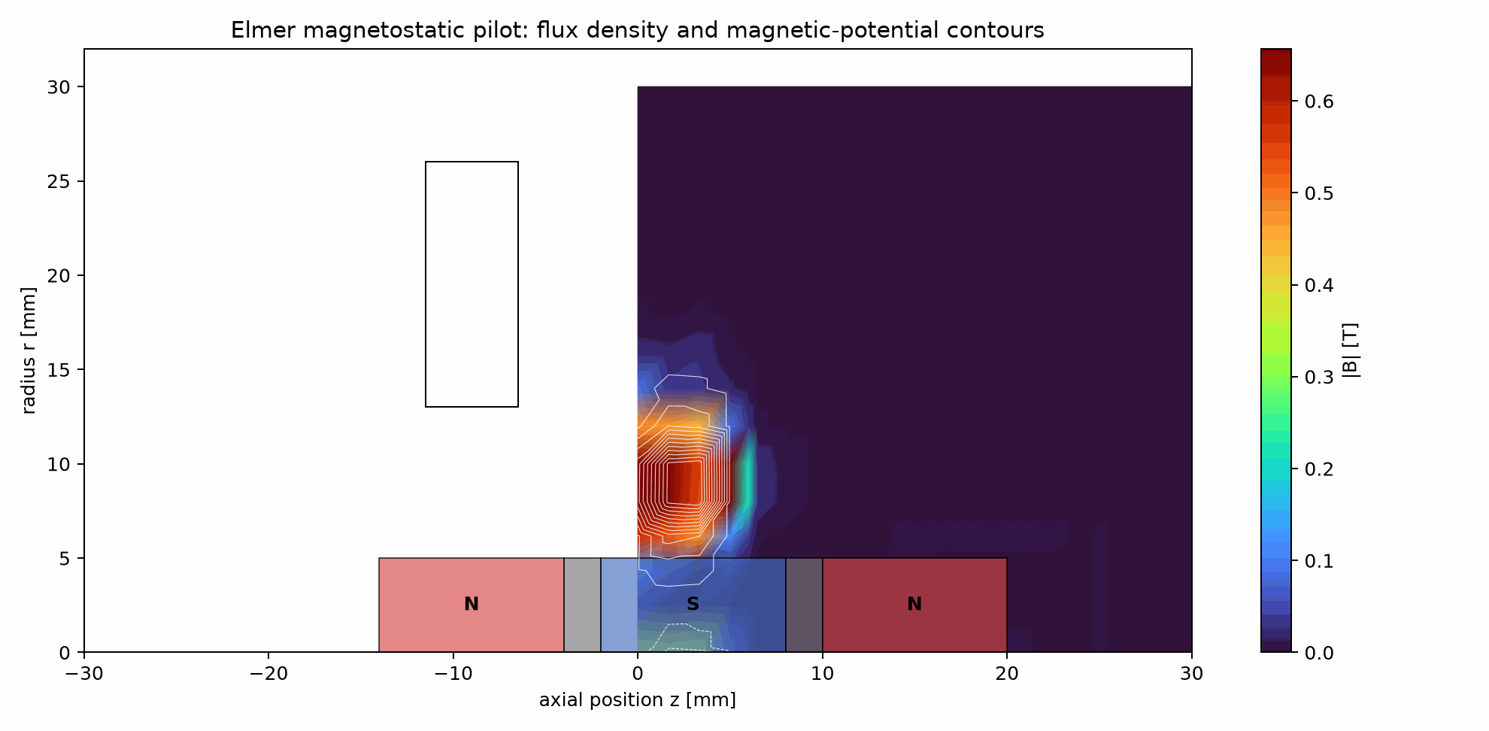
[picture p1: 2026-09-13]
elmer_coil_motion_study.gif

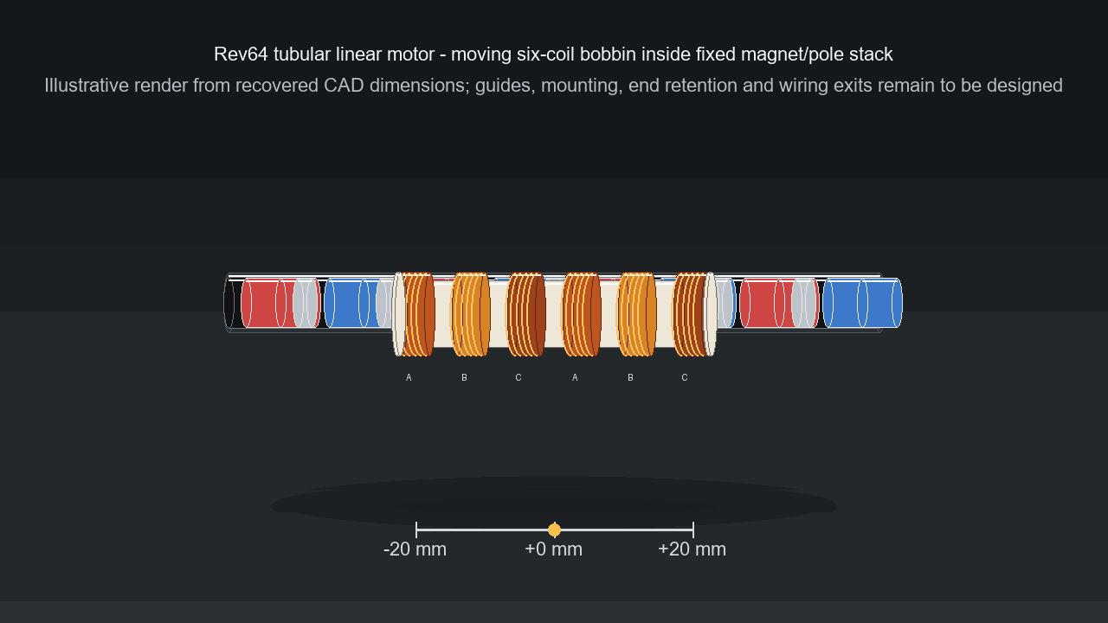
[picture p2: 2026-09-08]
media/rev64_real_life_motion.gif

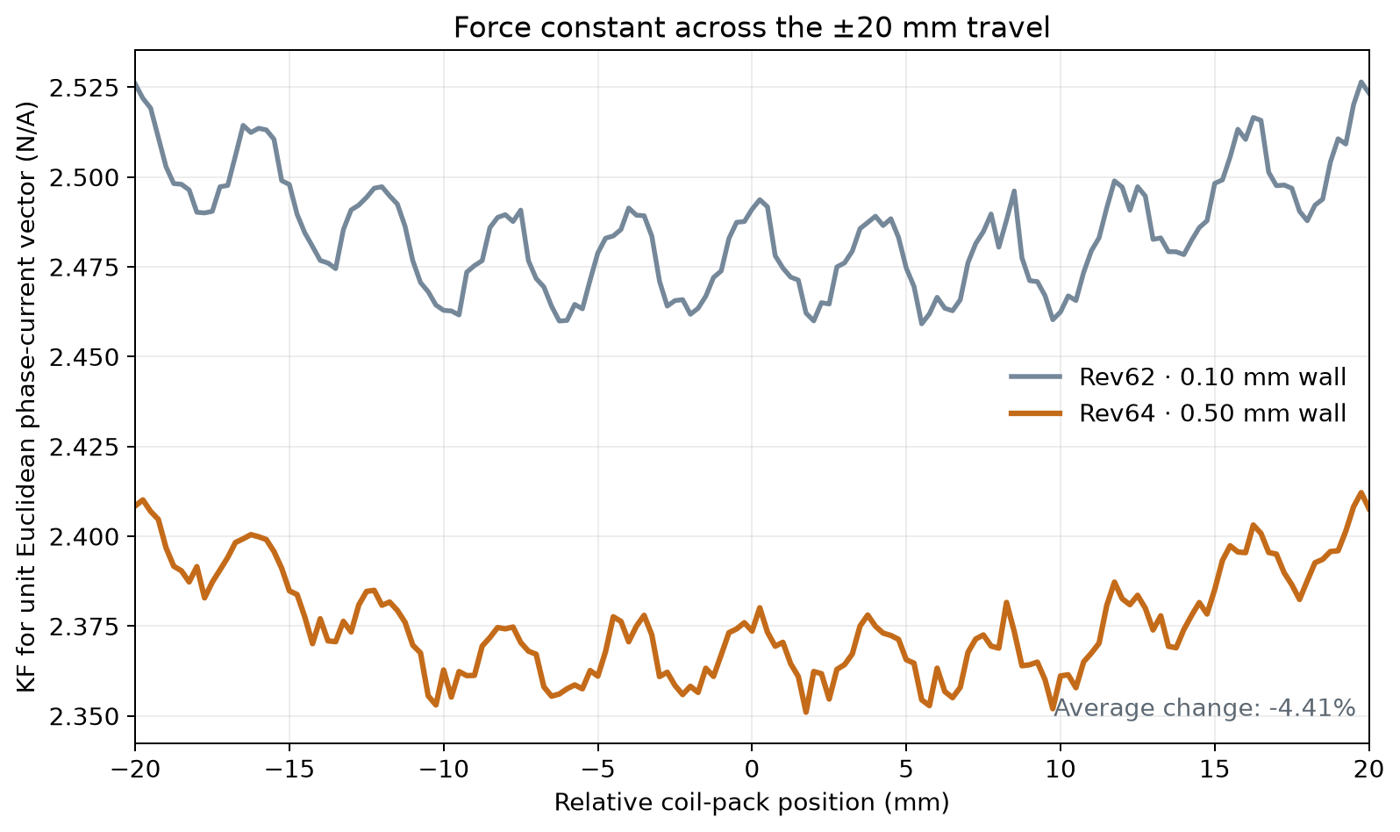
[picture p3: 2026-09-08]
simulation/rev64/Rev64_force_comparison.png

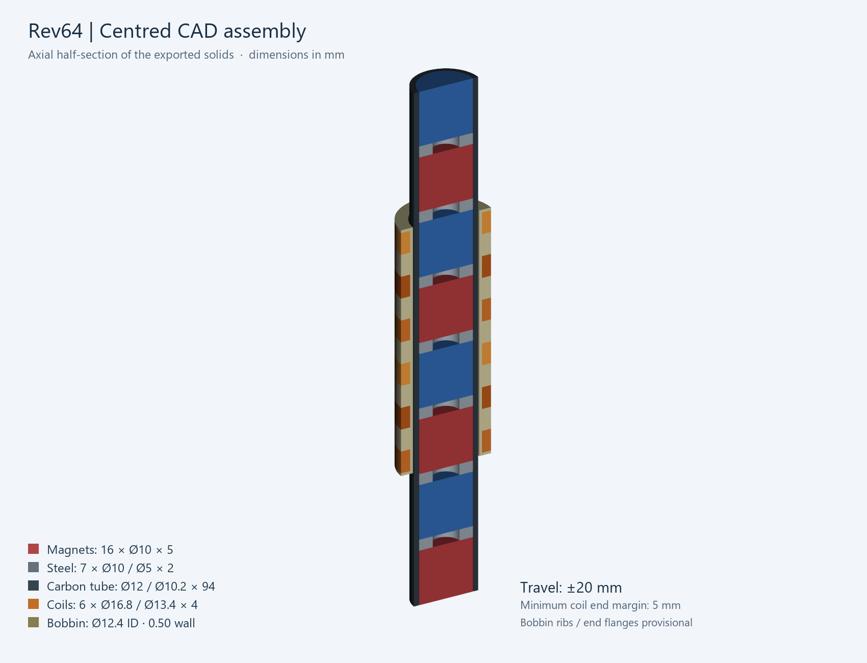
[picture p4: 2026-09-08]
cad/rev64/Rev64_CAD_cutaway.png

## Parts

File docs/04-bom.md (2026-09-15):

# Bill of materials and procurement

> **Historical Rev64 reference — not the active build.** This file describes the recovered six-coil / 80-turn Rev64 concept. It does not define the current nine-coil prototype. Use [the current prototype definition](11-current-build.md), [one-rail BOM](12-one-rail-bom.md), and [project audit](13-project-audit.md) for active work.

This is a complete register of known parts and unresolved systems, not a fully orderable production BOM. Blank prices and supplier fields mean unknown, not zero. No total build cost can be stated until those items are selected. The machine-readable [BOM](../bom/bom.json) retains supplier, part-number and cost fields for future quotes.

| ID | Item | Quantity | Specification | Status |
|---|---|---:|---|---|
| MAG-01 | Axially magnetized disc magnet | 16 each | Ø10 × 5 mm; N42SH model label; coating and supplier properties pending | Geometry defined; material certificate needed |
| POL-01 | Steel pole ring | 7 each | Ø10 OD × Ø5 ID × 2 mm; steel grade/B-H curve pending | Geometry defined; alloy pending |
| TUB-01 | Carbon tube | 1 each | Ø12 OD × Ø10.2 ID × 94 mm; layup and tolerances pending | Nominal geometry defined |
| BOB-01 | Six-pocket bobbin | 1 each | Ø12.4 ID, Ø13.4 base OD, Ø16.8 lands, 45 mm length; material/process/routes pending | Provisional custom part |
| WND-01 | Wound coil | 6 each | 80 turns; 4 mm width; Ø13.4–16.8 mm envelope | Trial winding required |
| WIRE-01 | Enamelled copper wire | TBD m | 0.250 mm bare; Grade 1; ≤0.281 mm finished; see calculated procurement length | Trial purchase only; full-build quantity calculated |
| BOB-TRIAL | Single-pocket trial former | 1 each | Rev64 pocket dimensions; actual lead/crossover design required | Additional prototype tooling; CAD not supplied |
| ADH-01 | Adhesive / impregnation | TBD quantity TBD | Compatibility, cure and thickness to be selected | Open |
| RET-01 | Stack retention and assembly fixture | TBD set TBD | End retention, magnet forces and tolerances to be designed | Open |
| GUIDE-01 | Linear guidance and carriage | TBD set TBD | Travel/load/stiffness, attachment and alignment to be specified | Open |
| STOP-01 | Mechanical stops and limit system | TBD set TBD | Usable stroke and failure behaviour to be specified | Open |
| LEAD-01 | Lead harness and terminals | TBD set TBD | Flexible leads, strain relief, connectors and phase topology to be detailed | Open |
| ENC-01 | Position sensor and mount | TBD set TBD | Accuracy, resolution, interface and datum pending | Open |
| DRV-01 | Three-phase current controller | 1 set | Current convention, inductance, bus voltage and encoder compatibility pending | Selection open; no rated current established |
| PSU-01 | Power supply and electrical protection | 1 set | Bus voltage/current, energy handling and protection pending | Selection open |
| TEMP-01 | Temperature sensors | TBD quantity TBD | Sensor placement, range and electrical isolation pending | Open |
| TEST-01 | Test equipment | 1 set | Suitable micrometer, resistance instrument, calibrated load cell, current measurement and temperature logging | Equipment checklist; not motor mass |

WND-01 is the wound subassembly and WIRE-01 is its raw material: do not count both as purchased finished coils plus purchased winding wire unless intentionally outsourcing spares. The trial former is additional tooling, not part of the 31-solid assembly. The reference annulus is excluded from the BOM.

Use the generated calculations for wire consumption and the separate full-build-plus-trial purchase allowance. Obtain a small trial spool before a production order. Confirm magnet coating dimensions, actual tube tolerances and bobbin process before releasing custom parts.

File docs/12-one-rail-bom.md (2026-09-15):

# One-rail bill of materials — X-axis reference

This BOM is for one complete 370 mm-travel motor rail. It is the purchase and build reference for the first X-axis prototype, not the total printer quantity. The twin Y rails need two matched copies of the magnet, tube, coil and encoder items, with 500 mm encoder scales.

| ID | Item | Qty to buy | Per rail used | Specification / decision |
|---|---|---:|---:|---|
| MAG-10-5 | N42SH disc magnet | 80 | 78 | 10 mm diameter x 5 mm thick, axial magnetisation, 150 C minimum, same supplier batch. Build 39 two-disc magnetic sections; retain 2 as spares. |
| SP-10-8-2 | Low-carbon steel spacer | 40 | 38 | 10 mm OD x 8 mm ID x 2 mm. Flat, burr-free carbon-steel washer or laser-cut shim; retain 2 spares. |
| TUBE-12-11 | Carbon tube | 1 x 500 mm | 1 x about 480 mm | 12 mm OD x 11 mm ID; do not final-cut until stack retention is proven. |
| END-RET | End-retention set | 2 | 2 | Custom nonmagnetic end plugs/retainers and assembly fixture. Design still required. |
| COIL-120 | Air coil | 9 | 9 | 13 mm bore x 5 mm wide, 120 turns, 8 mm centre pitch. |
| WIRE-AWG25 | Enameled copper wire | 100 m spool | 67.5 m nominal | AWG25 / 0.455 mm bare, about 0.496 mm finished, Class F minimum. Prepare 7.5 m per coil. |
| RESIN-EL160 | Impregnation resin | 1 kit | as needed | Easy Composites EL160; user has ordered this. Follow its cure and post-cure schedule. |
| CARRIER-9C | Nine-coil carrier | 1 | 1 | Custom nonmagnetic coil support and lead exit; CAD release pending after a physical coil trial. |
| RAIL-MGN12H | Linear guide | 1 | 1 | 450 mm MGN12H rail with carriage, aligned independently from the motor tube. |
| ENC-RLS | Linear encoder readhead | 1 | 1 | RLS `RLC2HDAD20B00C00`, 5 V TTL A/B/Z, 10 um resolution. |
| SCALE-RLS | Magnetic encoder scale | 1 | 1 | RLS `MS05AM450B0000`, 450 mm. |
| FOIL-RLS | Scale cover foil | 1 | 1 | RLS `CF050045`, 450 mm. |
| ENC-HARNESS | Encoder cable | 1 | 1 | Lightweight shielded five-core flexible cable: 5V, GND, A, B, Z. Keep away from motor phase wires. |
| TEMP-COIL | Coil temperature sensor | 1 | 1 | Fine Type-K thermocouple embedded on the outer surface of the centre coil before impregnation. |
| TEMP-TUBE | Tube temperature sensor | 1 | 1 | Fine Type-K thermocouple bonded to the carbon tube just beyond the coil pack; indirect magnet-temperature indication. |
| DRIVE | Motor controller channel | 1 | 1 | One MKS XDrive 3.6 channel at 48 V. The board may serve a second rail on its other channel. |
| BRAKE | Braking resistor | 1 | 1 | Sized after supply and regenerative-energy validation; required before high acceleration testing. |

## Assembly count check

- 39 sections x 2 magnets = 78 fitted magnets.
- 39 sections create 38 inter-section gaps = 38 fitted steel spacers.
- Stack length = 39 x 10 mm + 38 x 2 mm = 466 mm.
- Nine coils x 7.5 m prepared wire = 67.5 m; a 100 m spool covers winding, leads and a trial coil.

## External links

- [RLS RLC2HD product and configurator](https://www.rls.si/eng/rlc2hd-miniature-linear-and-rotary-pcb-level-incremental-magnetic-encoder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)
- [RLC2HD data sheet](https://cdn.rls.si/documents/datasheets/RLCD03_09_RLC2HD_datasheet_.pdf)
- [RLS MS magnetic scales](https://www.rls.si/eng/ms-scale)
- [ODrive incremental encoder wiring](https://docs.odriverobotics.com/v/latest/manual/hardware-config.html)
- [Makerbase ODrive/XDrive hardware repository](https://github.com/makerbase-motor/MKS-ODrive)
- [EL160 high-temperature laminating resin](https://www.easycomposites.eu/el160-high-temperature-epoxy-laminating-resin)

No magnet supplier is named here because stock and batch availability are still being confirmed. Order only after the supplier confirms N42SH (or an approved equivalent), axial magnetisation, 150 C working temperature and a single production batch for every magnet needed on the same rail.

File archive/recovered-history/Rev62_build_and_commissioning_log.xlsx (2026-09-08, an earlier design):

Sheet: Baseline
Rev62 build baseline
Frozen electromagnetic geometry and provisional commissioning limits.
Parameter | Value | Unit | Notes
Build ID | Rev62 |  | Robust real-wall bobbin
Carbon tube OD | 12.00 | mm | Measure actual tube before winding
Bobbin ID | 12.40 | mm | PEEK or G10
Bobbin wall | 0.10 | mm | Copper begins outside this wall
Copper inner radius | 6.30 | mm | Rev62 FEMM geometry
Copper outer radius | 8.40 | mm | Wound OD = 16.80 mm
Coil axial window | 4.00 | mm | Six coils at 8 mm pitch
Coil radial window | 2.10 | mm | Verify actual wire fit
Turns per coil | 80.00 | turns | A-B-C-A-B-C
Wire candidate | AWG30 |  | Confirm finished diameter <= 0.29 mm
Safe centred travel | 20.00 | mm | Use ±18 mm initial soft limits
KF minimum | 3.012 | N/A phase peak | Validated FEMM range
KF maximum | 3.094 | N/A phase peak | Validated FEMM range
Target carriage mass | 0.500 | kg | User design target
Target acceleration | 5.186 | m/s² | User design target
Required thrust | 2.593 | N | Mass × acceleration
Initial thermal-test current | 0.750 | A phase peak | Promote only after a stable thermal run
Acceleration candidate | 1.500 | A phase peak | Thermal-test candidate
Short peak candidate | 2.000 | A phase peak | Duty-limited until tested
Commissioning ceiling | 2.500 | A phase peak | Do not use without measured thermal data
Do not treat FEMM force confirmation as a physical thermal rating. The thermal log and release sheet establish the approved current limits.

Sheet: Build QC
Rev62 build quality control
Record measurements before potting or connecting the complete phase set.
Materials and dimensions
Item | Supplier / lot | Nominal | Measured | Unit | Requirement | Status | Notes
Carbon tube |  | 12 |  | mm OD | Fits bobbin without binding | Pending | Measure at multiple axial points
Bobbin ID |  | 12.4 |  | mm | Clearance to tube confirmed | Pending | PEEK or G10
Bobbin wall |  | 0.1 |  | mm | Copper start at r = 6.30 mm | Pending | Measure after machining
Bobbin pocket width |  | 4 |  | mm | Coil fits without pinching | Pending | Each pocket
AWG30 finished diameter |  | 0.29 |  | mm max | ≤ 0.29 mm target | Pending | Measure sample wire
Adhesive / impregnation |  |  |  |  | Temperature-compatible | Pending | Record product and cure
Trial coil and production-coil record
Coil | Phase | Axial centre (mm) | Turns target | Turns actual | Wire lot | Start lead | Finish lead | R coil (Ω) | Test °C | Insulation result | Status
C0 trial |  |  | 80 |  |  |  |  |  |  |  | Pending
C1 | A | 16 | 80 |  |  |  |  |  |  |  | Pending
C2 | B | 24 | 80 |  |  |  |  |  |  |  | Pending
C3 | C | 32 | 80 |  |  |  |  |  |  |  | Pending
C4 | A | 40 | 80 |  |  |  |  |  |  |  | Pending
C5 | B | 48 | 80 |  |  |  |  |  |  |  | Pending
C6 | C | 56 | 80 |  |  |  |  |  |  |  | Pending
Phase polarity gate: connect C1-C4, C2-C5, and C3-C6 in series only after low-current induced-voltage or force-direction testing.

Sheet: Thermal Log
Rev62 thermal commissioning log
Use the final mounting and worst expected chamber condition. Record raw readings rather than interpolated values.
Run ID | Date | Build ID | Assembly state | Chamber °C | Phase peak A | Phase RMS A | Phase R Ω | Copper °C from R | Max coil NTC °C | Carrier °C | Elapsed min | Duty / waveform | Copper loss W | Estimated Rθ K/W | Steady state | Stop reason | Result
T01 |  | Rev62 |  |  |  |  |  |  |  |  |  |  |  |  | Pending |  | Pending
T02 |  | Rev62 |  |  |  |  |  |  |  |  |  |  |  |  | Pending |  | Pending
T03 |  | Rev62 |  |  |  |  |  |  |  |  |  |  |  |  | Pending |  | Pending
T04 |  | Rev62 |  |  |  |  |  |  |  |  |  |  |  |  | Pending |  | Pending
T05 |  | Rev62 |  |  |  |  |  |  |  |  |  |  |  |  | Pending |  | Pending
T06 |  | Rev62 |  |  |  |  |  |  |  |  |  |  |  |  | Pending |  | Pending
T07 |  | Rev62 |  |  |  |  |  |  |  |  |  |  |  |  | Pending |  | Pending
T08 |  | Rev62 |  |  |  |  |  |  |  |  |  |  |  |  | Pending |  | Pending
T09 |  | Rev62 |  |  |  |  |  |  |  |  |  |  |  |  | Pending |  | Pending
T10 |  | Rev62 |  |  |  |  |  |  |  |  |  |  |  |  | Pending |  | Pending
T11 |  | Rev62 |  |  |  |  |  |  |  |  |  |  |  |  | Pending |  | Pending
T12 |  | Rev62 |  |  |  |  |  |  |  |  |  |  |  |  | Pending |  | Pending
T13 |  | Rev62 |  |  |  |  |  |  |  |  |  |  |  |  | Pending |  | Pending
T14 |  | Rev62 |  |  |  |  |  |  |  |  |  |  |  |  | Pending |  | Pending
T15 |  | Rev62 |  |  |  |  |  |  |  |  |  |  |  |  | Pending |  | Pending
T16 |  | Rev62 |  |  |  |  |  |  |  |  |  |  |  |  | Pending |  | Pending
T17 |  | Rev62 |  |  |  |  |  |  |  |  |  |  |  |  | Pending |  | Pending
T18 |  | Rev62 |  |  |  |  |  |  |  |  |  |  |  |  | Pending |  | Pending
T19 |  | Rev62 |  |  |  |  |  |  |  |  |  |  |  |  | Pending |  | Pending
T20 |  | Rev62 |  |  |  |  |  |  |  |  |  |  |  |  | Pending |  | Pending
T21 |  | Rev62 |  |  |  |  |  |  |  |  |  |  |  |  | Pending |  | Pending
T22 |  | Rev62 |  |  |  |  |  |  |  |  |  |  |  |  | Pending |  | Pending
T23 |  | Rev62 |  |  |  |  |  |  |  |  |  |  |  |  | Pending |  | Pending
T24 |  | Rev62 |  |  |  |  |  |  |  |  |  |  |  |  | Pending |  | Pending
T25 |  | Rev62 |  |  |  |  |  |  |  |  |  |  |  |  | Pending |  | Pending
Thermal reference | Value
Estimated phase R20 (Ω) | 2.63
Copper temperature limit (°C) | 120
Steady-state criterion | <1 °C rise over 10 min

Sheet: Force Travel
Rev62 force and travel validation
Force targets are FEMM values. Record the applied phase-peak scale and load-cell calibration used for each run.
Test ID | Date | Position target mm | Encoder actual mm | IA unit | IB unit | IC unit | Phase peak A | F+ N | F- N | PM odd force N | Even force N | FEMM target N | Error % | Load-cell calibration | Travel limit check | Result
F01 |  | -20 |  | -0.5373059453 | -0.4617419485 | 0.9990478938 | 0.1 |  |  |  |  | 0.3093629933 |  |  | Pending | Pending
F02 |  | 0 |  | 0.5015468603 | -0.9999984032 | 0.4984515429 | 0.1 |  |  |  |  | 0.3050900371 |  |  | Pending | Pending
F03 |  | 20 |  | 0.998942741 | -0.4596586816 | -0.5392840594 | 0.1 |  |  |  |  | 0.3090534289 |  |  | Pending | Pending
Initial encoder soft limits: −18 mm to +18 mm relative to magnetic centre. Expand only after repeatability and end-margin checks.

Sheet: Release
Rev62 release checklist
Complete this sheet only after the raw build, thermal, and force records are attached to the same Build ID.
Gate | Requirement | Evidence / run ID | Owner | Date | Disposition
Wire fit | 80-turn trial coil meets geometry and insulation requirements |  |  |  | Pending
Coils | Six coil resistances and insulation checks recorded |  |  |  | Pending
Polarity | All phase pairs confirmed at low current |  |  |  | Pending
Encoder | Datum and ±18 mm soft limits verified |  |  |  | Pending
Force | Measured force at −20, 0, +20 mm recorded |  |  |  | Pending
Thermal 0.75/1.0 A | Thermal steady-state tests completed |  |  |  | Pending
Current limits | Continuous and peak limits documented |  |  |  | Pending
Mechanical | Leads, strain relief, and clearances inspected |  |  |  | Pending
Deviations | All deviations documented and closed |  |  |  | Pending
Release | Motor approved for next build stage |  |  |  | Pending

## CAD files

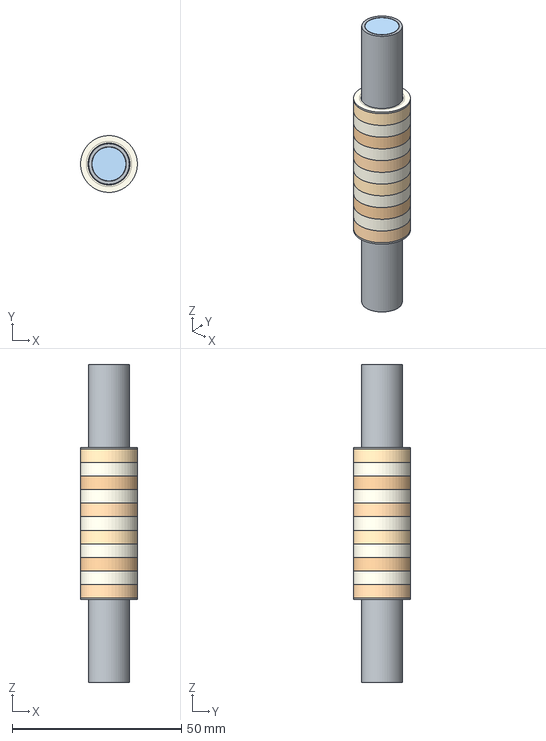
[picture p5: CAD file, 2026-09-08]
cad/rev64/Rev64_centered_assembly.step
16.8 x 16.8 x 94.0 mm

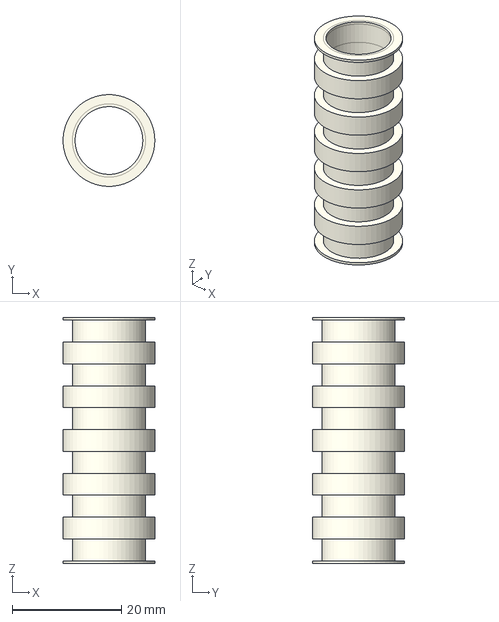
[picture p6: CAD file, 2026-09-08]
cad/rev64/Rev64_bobbin_provisional.step
16.8 x 16.8 x 45.0 mm

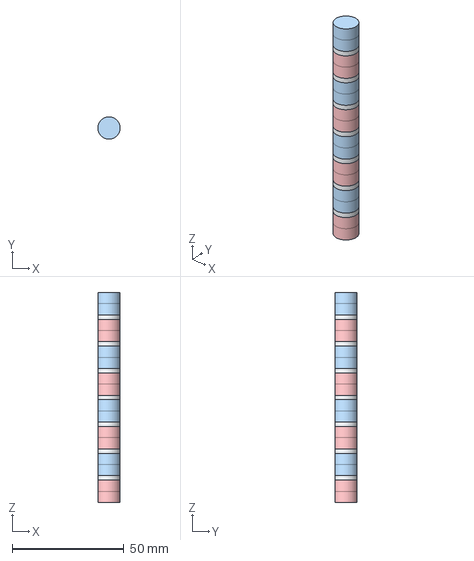
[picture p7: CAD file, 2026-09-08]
cad/rev64/Rev64_magnet_steel_stack.step
9.99 x 10.00 x 94.0 mm

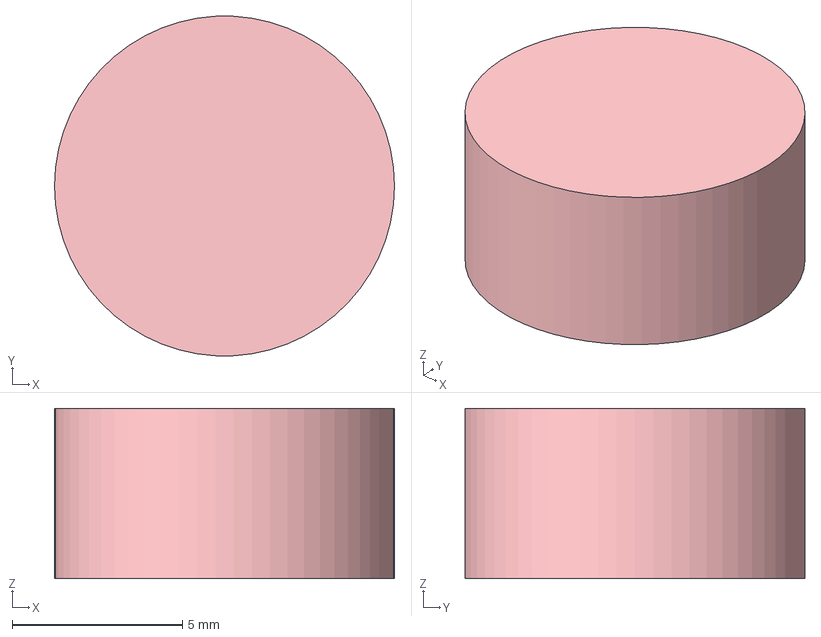
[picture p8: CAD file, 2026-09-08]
cad/rev64/Rev64_magnet_OD10_L5.step
10.0 x 9.99 x 5.00 mm

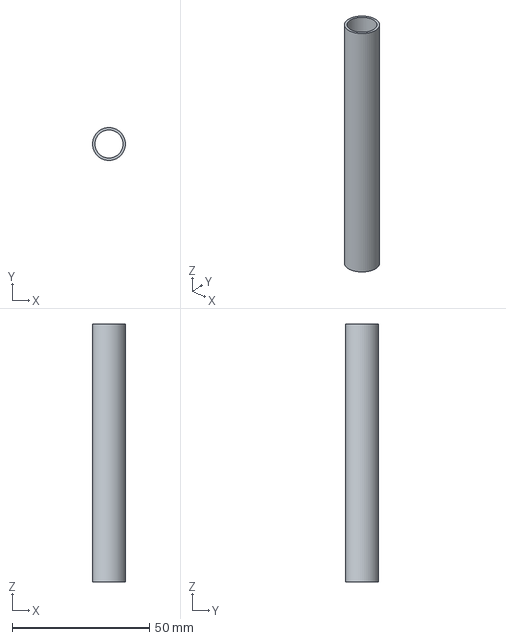
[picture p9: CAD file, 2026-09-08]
cad/rev64/Rev64_carbon_tube.step
12.0 x 12.0 x 94.0 mm

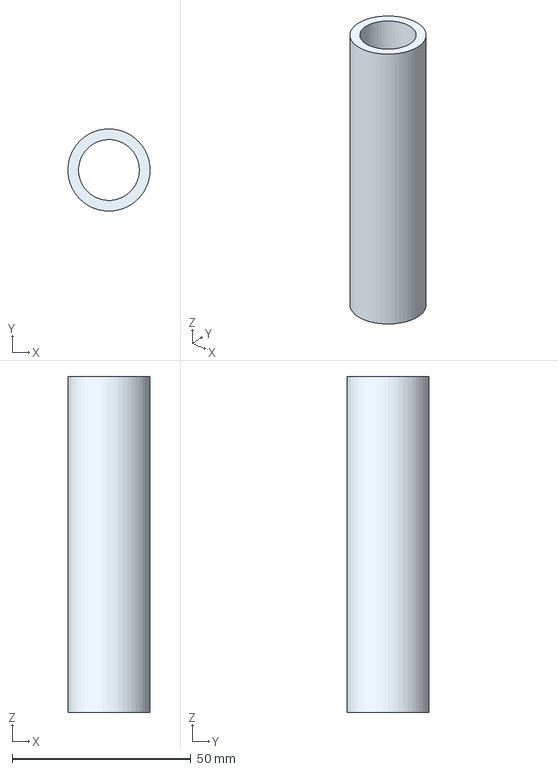
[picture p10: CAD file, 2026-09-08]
cad/rev64/Rev64_unassigned_outer_envelope_REFERENCE_ONLY.step
23.0 x 23.0 x 94.0 mm

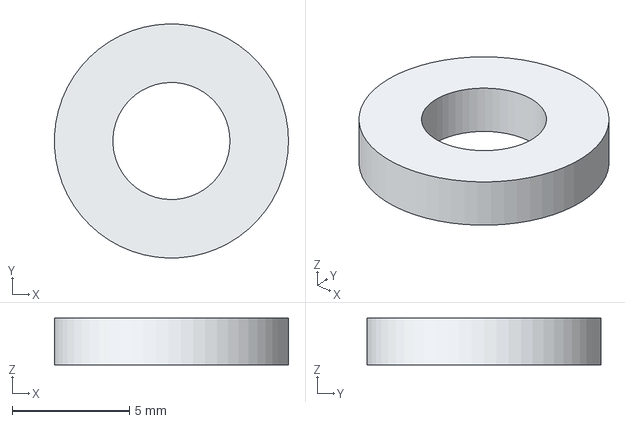
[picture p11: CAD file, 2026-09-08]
cad/rev64/Rev64_pole_ring_ID5_OD10_L2.step
9.99 x 10.00 x 2.00 mm

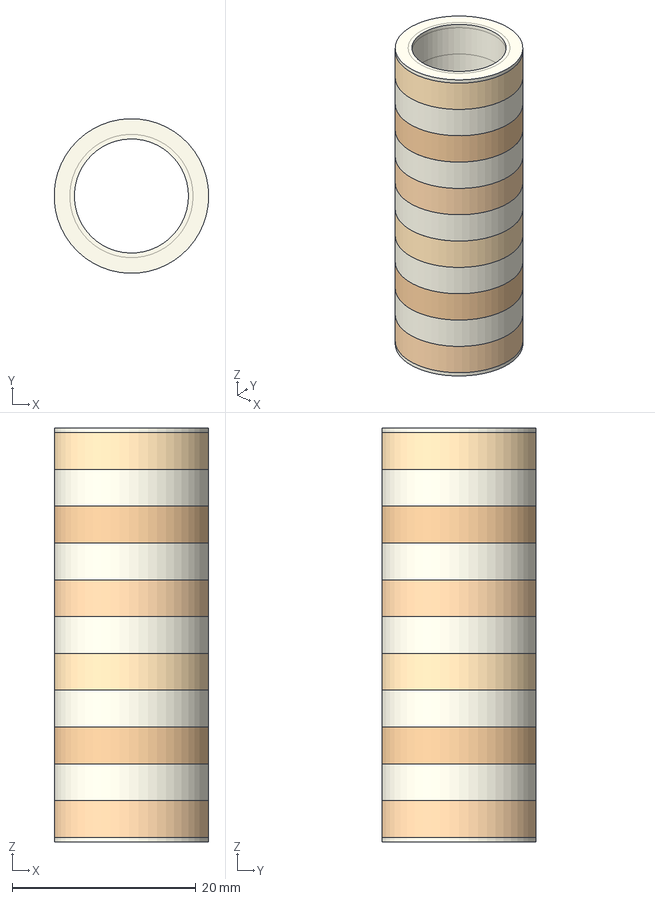
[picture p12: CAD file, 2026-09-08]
cad/rev64/Rev64_moving_coil_pack.step
16.8 x 16.8 x 45.0 mm

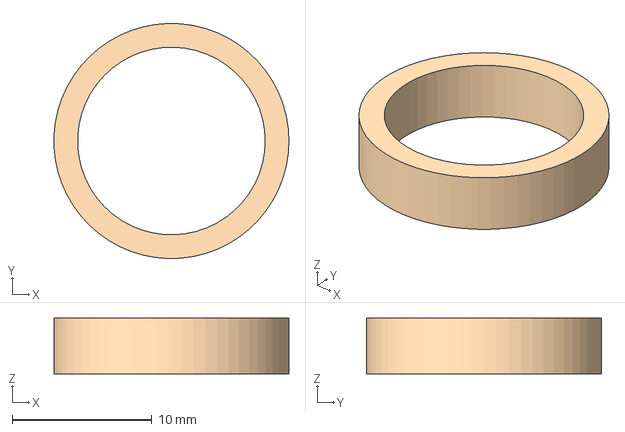
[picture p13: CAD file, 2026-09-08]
cad/rev64/Rev64_coil_envelope_ID13p4_OD16p8_L4.step
16.8 x 16.8 x 4.00 mm

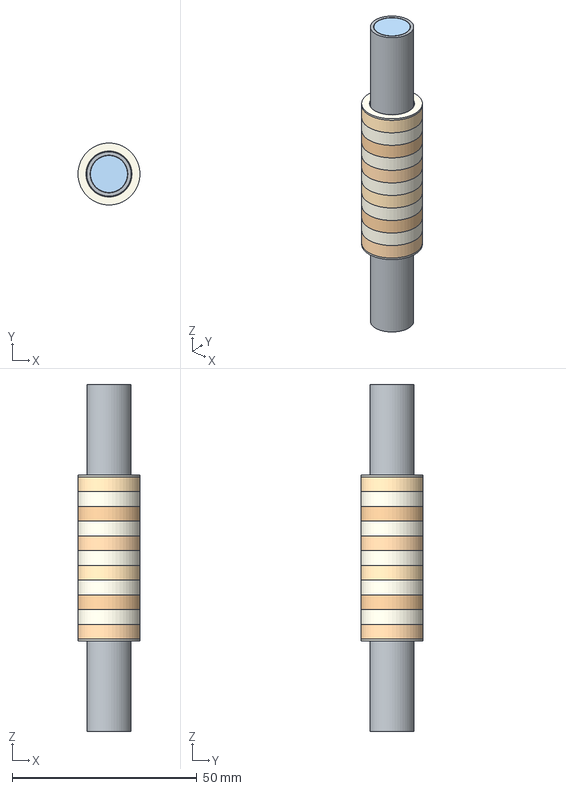
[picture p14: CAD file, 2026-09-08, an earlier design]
cad/rev62/Rev62_centered_assembly.step
16.8 x 16.8 x 94.0 mm

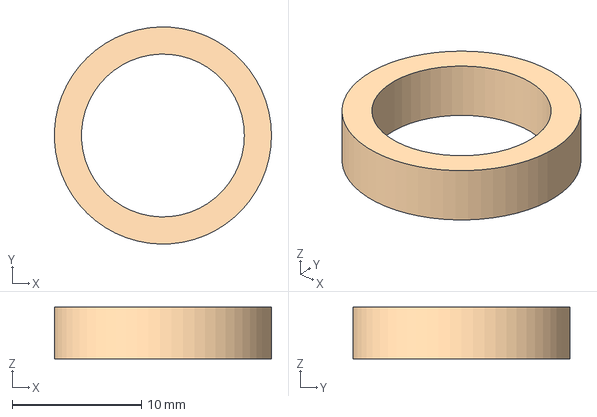
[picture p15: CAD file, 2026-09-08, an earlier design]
cad/rev62/Rev62_coil_envelope_ID12p6_OD16p8_L4.step
16.8 x 16.8 x 4.00 mm

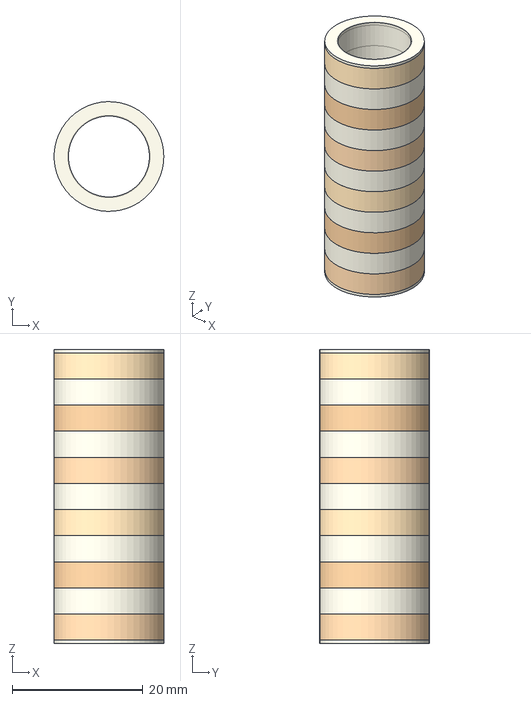
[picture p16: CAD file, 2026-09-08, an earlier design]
cad/rev62/Rev62_moving_coil_pack.step
16.8 x 16.8 x 45.0 mm

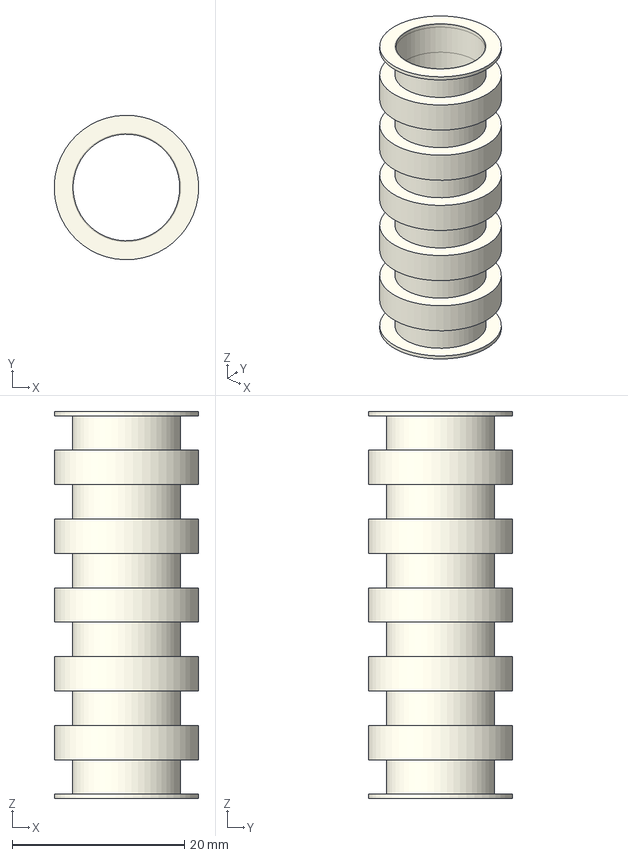
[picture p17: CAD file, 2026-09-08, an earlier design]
cad/rev62/Rev62_bobbin_provisional.step
16.8 x 16.8 x 45.0 mm

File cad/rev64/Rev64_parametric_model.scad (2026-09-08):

// Rev64: 0.5 mm bobbin wall. Units mm; motor axis Z.
// STEP exports contain exact solids. Lands/end flanges remain provisional.
/* [Display] */
part="assembly"; // [assembly,bobbin,coils,stack,tube,magnet,pole,reference]
cutaway=false;
position=0; // [-20:0.25:20]
show_reference=false;
/* [Winding pack] */
coil_count=6;
coil_pitch=8;
coil_width=4;
bobbin_id=12.4;
bobbin_wall=0.5;
coil_od=16.8;
end_flange=0.5;
/* [Stationary stack] */
magnet_od=10;
magnet_piece_length=5;
magnet_pairs=8;
pole_id=5;
pole_width=2;
tube_id=10.2;
tube_od=12;
/* [Reference envelope, no assigned material] */
reference_id=17;
reference_od=23;
/* [Hidden] */
$fn=192;
coil_id=bobbin_id+2*bobbin_wall;
stack_length=magnet_pairs*2*magnet_piece_length+(magnet_pairs-1)*pole_width;
pack_length=(coil_count-1)*coil_pitch+coil_width;
centres=[for(i=[0:coil_count-1]) (i-(coil_count-1)/2)*coil_pitch];
phase_colors=[[0.87,0.47,0.17],[0.75,0.36,0.10],[0.95,0.62,0.25]];
assert(bobbin_id>tube_od && bobbin_wall>0);
assert(coil_pitch>=coil_width && coil_od>coil_id);
assert(abs(position)+pack_length/2+end_flange<=stack_length/2,"Former exceeds stack length");
module ring(id,od,z,h) {
    translate([0,0,z]) difference() {
        cylinder(d=od,h=h);
        if(id>0) translate([0,0,-0.01]) cylinder(d=id,h=h+0.02);
    }
}
module former() {
    union() {
        ring(bobbin_id,coil_id,-pack_length/2-end_flange,pack_length+2*end_flange);
        ring(bobbin_id,coil_od,-pack_length/2-end_flange,end_flange);
        for(i=[0:coil_count-2]) ring(bobbin_id,coil_od,centres[i]+coil_width/2,coil_pitch-coil_width);
        ring(bobbin_id,coil_od,pack_length/2,end_flange);
    }
}
module winding_pack() {
    for(i=[0:coil_count-1]) color(phase_colors[i%3])
        ring(coil_id,coil_od,centres[i]-coil_width/2,coil_width);
}
module magnetic_stack() {
    for(i=[0:magnet_pairs-1]) {
        z=-stack_length/2+i*(2*magnet_piece_length+pole_width);
        for(j=[0:1]) color(i%2==0?[0.72,0.24,0.26]:[0.20,0.43,0.72])
            ring(0,magnet_od,z+j*magnet_piece_length,magnet_piece_length);
        if(i<magnet_pairs-1) color([0.62,0.66,0.70])
            ring(pole_id,magnet_od,z+2*magnet_piece_length,pole_width);
    }
}
module selected_model() {
    if(part=="assembly" || part=="stack") magnetic_stack();
    if(part=="assembly" || part=="tube") color([0.20,0.24,0.28]) ring(tube_id,tube_od,-stack_length/2,stack_length);
    if(part=="assembly" || part=="coils") translate([0,0,position]) winding_pack();
    if(part=="assembly" || part=="bobbin") translate([0,0,position]) color([0.85,0.82,0.65]) former();
    if(part=="magnet") ring(0,magnet_od,0,magnet_piece_length);
    if(part=="pole") ring(pole_id,magnet_od,0,pole_width);
    if(part=="reference") ring(reference_id,reference_od,-stack_length/2,stack_length);
}
difference() {
    selected_model();
    if(cutaway) translate([-reference_od,0,-stack_length]) cube([2*reference_od,reference_od,2*stack_length]);
}
if(show_reference && part=="assembly") %ring(reference_id,reference_od,-stack_length/2,stack_length);

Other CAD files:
cad/rev62/Rev62_magnet_steel_stack.step
cad/rev62/Rev62_carbon_tube.step
cad/rev62/Rev62_unassigned_outer_envelope_REFERENCE_ONLY.step
cad/rev62/Rev62_pole_ring_ID5_OD10_L2.step
cad/rev62/Rev62_magnet_OD10_L5.step
cad/rev62/Rev62_parametric_model.scad

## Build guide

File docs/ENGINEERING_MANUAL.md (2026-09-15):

# Tubular linear motor — engineering manual

> **Historical Rev64 reference — not the active build.** This file describes the recovered six-coil / 80-turn Rev64 concept. It does not define the current nine-coil prototype. Use [the current prototype definition](11-current-build.md), [one-rail BOM](12-one-rail-bom.md), and [project audit](13-project-audit.md) for active work.

Revision 64 documentation, with Revision 62 history. Prototype definition; no physical qualification established.

See [repository overview](../README.md) and [generated calculations](../calculations/results.md).

---

## Design and coordinate system

### Architecture

The permanent-magnet/steel stack and carbon tube are stationary. Six wound coils and their common nonmagnetic bobbin move along Z. FEMM uses an axisymmetric cross-section with horizontal coordinate r and vertical coordinate z; the CAD axis is Z. All geometry files use millimetres. Force derivatives convert displacement to metres.

The carbon tube separates the magnet stack from the bobbin bore. A bore clearance is not a designed bearing: radial guidance, concentricity and lateral load capacity remain unspecified.

```mermaid
flowchart LR
  Drive[Three-phase current drive] --> Coils[Six coils on moving bobbin]
  Encoder[Position sensor: selection open] --> Drive
  Stack[Fixed alternating magnet pairs and steel rings] --> Field[Radial field through coil region]
  Field --> Force[Axial force]
  Coils --> Force
  Force --> Carriage[Carriage and guidance: design open]
```

### Parts and datums

| Item | Geometry / position |
|---|---|
| Magnet pairs | Eight 10 mm sections; each made from two Ø10 × 5 mm discs |
| Pair centres | Z = −42, −30, −18, −6, 6, 18, 30, 42 mm |
| Magnetization | First pair +Z, then −Z, +Z, −Z, +Z, −Z, +Z, −Z |
| Pole rings | Ø10 outside, Ø5 bore, 2 mm thick, centres −36, −24, −12, 0, 12, 24, 36 mm |
| Stack and tube ends | Z = −47 and +47 mm |
| Coil centres | Z = −20, −12, −4, 4, 12, 20 mm at displacement zero |
| Bobbin ends | Z = −22.5 and +22.5 mm at displacement zero |
| Coil pack ends | Z = −22 and +22 mm at displacement zero |

Both discs in each pair have the same axial magnetization. The CAD treats their interface as zero thickness. Adhesive or actual gaps must be added to the stack tolerance and electromagnetic models if used. Magnetization direction is a vector; an N/S marking procedure must be established and verified with a known pole reference before assembly.

The nominal assembly has 31 solids: 16 magnets + 7 steel rings + 1 tube + 6 winding envelopes + 1 bobbin. The winding envelopes occupy the allowable winding volume, not the actual copper fill. Their volume cannot be multiplied by copper density to obtain actual winding mass.

### Geometric travel

At either ±20 mm extreme, the farthest winding edge is 42 mm from the stack centre, leaving 5 mm to the stack end. The bobbin edge reaches 42.5 mm, leaving 4.5 mm. These are axial overlap margins only. The original commissioning notes proposed initial ±18 mm soft limits; these remain a proposed commissioning setting pending end-stop and encoder design.

### Reference envelope

The Ø17 bore / Ø23 outside annulus is unassigned FEMM reference geometry and is excluded from the physical STEP assembly. No steel yoke or centre through-rod is established by the source model. Introducing either requires a fresh electromagnetic and mechanical evaluation.

---

## Revision history and workbook audit

### Revision 62 to Revision 64

| Parameter | Rev62 | Rev64 |
|---|---:|---:|
| Bobbin bore, mm | 12.4 | 12.4 |
| Bobbin base wall, mm | 0.10 | 0.50 |
| Winding inside diameter, mm | 12.6 | 13.4 |
| Winding outside diameter, mm | 16.8 | 16.8 |
| Radial winding window, mm | 2.1 | 1.7 |
| Axial winding window, mm | 4 | 4 |
| Window area, mm² | 8.4 | 6.8 |
| Turns per coil | 80 | 80 |
| Coil pitch, mm | 8 | 8 |

The wall is five times as thick; available winding-window cross-section decreases by 19.0476%. Increased wall thickness is not itself proof of adequate strength. The magnet stack, carbon tube, coil axial positions and nominal travel are unchanged. The archived mean force constant falls from 2.485202 to 2.375722 N/A of current-vector magnitude, a 4.4053% decrease.

Revision 62 CAD is already centred, but its original parent FEMM coil centres were 16, 24, 32, 40, 48, 56 mm. Its sweep translated the pack by −36 mm. Revision 64 FEMM is already centred; repeating that translation is incorrect.

### What the recovered workbook establishes

The preserved `archive/recovered-history/Rev62_build_and_commissioning_log.xlsx` was inspected across all five worksheets. It is a commissioning template, not evidence of a completed build.

| Sheet / cells | Findings and implications |
|---|---|
| Baseline B9:B15 | 0.10 mm wall, 6.3 mm copper start radius, 2.1 mm radial window and generic AWG30 candidate are Rev62 values. They must not be applied to Rev64. |
| Baseline B19:B21 | Historical target mass 0.5 kg and acceleration 5.186 m/s² imply 2.593 N inertia-only thrust. Orientation, friction and total moving mass need confirmation. |
| Baseline B22:B25 | 0.75, 1.5, 2.0 and 2.5 A phase-peak entries are proposed test/candidate values, not approved ratings. |
| Build QC D7:D12; E17:K23 | Actual dimensions, winding counts, resistances and insulation results are empty. Status entries are Pending. |
| Build QC C18:C23 | Coil positions use the old uncentred FEMM frame (16 to 56 mm). New records use centred coordinates. |
| Thermal Log B34:B36 | 2.63 Ω is an estimated phase resistance, 120°C is an old proposed copper limit, and <1°C rise over 10 minutes is an old steady-state criterion. None proves safe operation. |
| Thermal Log rows 6:30 | Raw test inputs are blank. Formulas are present, but no measured thermal run is recorded. |
| Force Travel rows 6:8 | Measured F+ and F− are blank. Force targets and current vectors belong to the earlier revision. |
| Release rows 6:15 | Every disposition is Pending; no release evidence is filled. |

The old thermal temperature estimate divides by an estimated reference resistance. For new tests, measure the same winding's resistance and reference temperature first. The old force target cells are constants and do not automatically scale if the current input changes. New record guidance requires recalculating each target for the actual current and position.

### Recovery provenance

The recovered Rev62 parent FEMM file exactly matches the SHA-256 parent fingerprint recorded in Rev64's source check. The Rev62 CAD README in the later supplied archive is identical to the earlier recovered note. Raw source files are preserved without revision substitutions. Revision 63 direct-force files are retained as history and are not used as Rev64 results.

---

## Calculations and assumptions

Run `python tools/calculate.py` from the repository root to generate [results](../calculations/results.md) and [machine-readable values](../calculations/results.json). Inputs are in [parameters.json](../calculations/parameters.json). The calculator rejects impossible layer counts and gross overfill; passing those checks does not prove a manufacturable winding.

### Source hierarchy and units

Geometry comes from Rev64 CAD parameters and FEMM coordinates. Force comes from archived simulation CSVs. Wire dimensions and resistance per metre come from the linked Elektrisola IEC table. Extra lead length, procurement allowance, copper density and temperature coefficient are explicitly stated estimates. The historical mass and acceleration are workbook targets, not newly confirmed requirements. SI units are used for electromagnetic and dynamic equations; geometry uses mm with explicit conversions.

### Geometry

Let N_c be coil count, p coil pitch, w coil width, t bobbin wall and D_b bobbin bore.

- Stack length = 16 × 5 + 7 × 2 = 94 mm.
- Coil-pack length = (N_c − 1)p + w = 44 mm.
- Bobbin length = 44 + 2 × 0.5 = 45 mm.
- Coil ID = D_b + 2t = 13.4 mm.
- Radial window h = (16.8 − 13.4)/2 = 1.7 mm.
- Window cross-section = wh = 6.8 mm².
- Minimum winding end margin = 94/2 − 20 − 44/2 = 5 mm.
- Minimum bobbin end margin = 94/2 − 20 − 45/2 = 4.5 mm.
- Magnet-to-tube radial gap = (10.2 − 10)/2 = 0.10 mm.
- Tube-to-bobbin radial gap = (12.4 − 12)/2 = 0.20 mm.

For an annular component, V = π(D_o² − D_i²)L/4. Use D_i = 0 for a solid magnet disc. Bobbin volume equals the base sleeve plus the radial material above the base over the five 4 mm lands and two 0.5 mm flanges. Source component volumes are independently checked against these formulas.

### Winding fit

At finished wire diameter d_f = 0.281 mm, the ordered rectangular plan is 14 + 14 + 13 + 13 + 13 + 13 = 80 turns. Six layers occupy 6d_f = 1.686 mm radially. The widest layer occupies 14d_f = 3.934 mm axially. Nominal allowances are 0.014 mm radially and 0.066 mm axially.

The purely geometric diameter ceiling is min(1.7/6, 4/14) = 0.283333 mm, before any allowance. The specified 0.281 mm maximum is below that ceiling but only barely. Real crossovers, irregular stacking, enamel variation, bobbin tolerance and impregnation consume clearance. No extra insulation or adhesive allowance is built into the nominal fit.

Bare copper area A = πd_bare²/4 = 0.0490874 mm². Cross-sectional copper fill fraction = 80A/(4 × 1.7) ≈ 57.75%. This area fraction does not describe packing difficulty by itself. It also is not exactly the winding-volume fill when the turn counts vary by layer radius.

### Wire length, resistance and mass

For layer j starting at zero, centre diameter D_j = D_coil_ID + (2j + 1)d_f. Approximate turn length is πD_j. The model uses L_winding = Σ(n_j πD_j)/1000 metres. It neglects the tiny helical correction and excludes crossovers and terminals.

The explicit allowance is 0.20 m extra wire per coil. This is a planning input, not a recovered lead-routing dimension. Total wire per coil = L_winding + allowance. Production consumption is six times that value. A separate 20% procurement allowance is applied only to purchase length, not electrical resistance or copper mass. One trial coil adds its own consumption before that allowance.

R_coil,20 = wire length × 0.3482 Ω/m. The supplier table's 0.3345–0.3628 Ω/m range produces an estimated resistance band for the same length. Each series phase has two coils, so R_phase = 2R_coil, plus any extra interconnect resistance not included in the allowance. For a balanced star connection measured between two terminals with the third open, R_line-line = 2R_phase. These relations do not apply unchanged to delta wiring.

Copper mass = A × length × density after unit conversion. Density 8.9 g/cm³ is an estimate. Insulation, solder, lead dress, bobbin, carriage and adhesive are excluded. Bobbin CAD volume is available, but bobbin mass remains V × selected-material density. Total moving mass is unavailable until the mechanical BOM is specified.

### Force and current definitions

For phase permanent-magnet flux linkages λ_A, λ_B, λ_C in Wb-turn and displacement x in metres, define g = dλ/dx. Remove the common-mode component: p = g − mean(g)[1,1,1]. Then K = ||p||₂ and u = p/K. The optimum balanced current is i = I_vector u, satisfying sum(i) = 0 and ||i||₂ = I_vector. Its PM force prediction is F = g·i = K I_vector.

The archived script uses centred differences at interior samples and one-sided differences at ±20 mm. Displacement spacing is 0.25 mm. These gradients and normalized currents are checked again from the saved flux data.

For the conventional balanced sinusoidal scaling, I_vector = sqrt(3/2) I_phase_peak, and each phase RMS over a sinusoidal cycle is I_phase_peak/sqrt(2). Therefore K_phase_peak_equivalent = sqrt(3/2) K. The saved optimum vectors are not a guarantee that an arbitrary fixed sinusoidal commutation law produces the same force. At standstill, the individual DC phase values differ from their over-cycle RMS values. Always state which current convention is used.

Direct-force validation uses F_PM_odd = [F(+i) − F(−i)]/2 and F_even = [F(+i) + F(−i)]/2. Relative difference = 100(F_PM_odd − K)/K for the saved unit-vector currents. Three checks are consistency evidence, not a full mesh-convergence study or measured force map.

### Copper loss and temperature

For equal phase resistance R_phase and arbitrary instantaneous currents, P_copper = R_phase(i_A² + i_B² + i_C²) = R_phase I_vector². Under equivalent sinusoidal phase-peak scaling this becomes 1.5 R_phase I_phase_peak². Current scenarios in the generated table are arithmetic examples, not approved operating limits.

R(T) = R20[1 + α(T − 20°C)], using α = 0.00393/K as an estimate. A measured reference at T_ref gives T = 20 + {(R/R_ref)[1 + α(T_ref − 20)] − 1}/α. Measure after settling and account for lead/contact resistance. This estimates average copper temperature, not the hottest turn.

At thermal steady state, Rθ ≈ (T − T_ambient)/P. With equal phase resistances, a provisional current calculation would be I_phase_peak ≤ sqrt[(T_limit − T_ambient)/(1.5 R_phase(T_limit) Rθ)]. Rθ, ambient worst case, material-compatible T_limit and duty cycle are missing, so no continuous-current result is assigned. The old 120°C workbook entry is not an approved limit.

### Load, acceleration and orientation

Historical targets give F_inertia = ma = 0.5 × 5.186 = 2.593 N. A vertical upward acceleration requires F = m(a + g) + friction + external load; with gravity alone added, F = 7.496325 N. Horizontal force ignores gravity along the axis but still needs friction and cable load. The generated estimates divide these loads by the minimum archived K to show conservative position-based current within this first-pass simulation. They do not include a design margin or magnetic-temperature derating.

Holding force on a vertical axis is mg even at zero acceleration. A commanded current failure cannot be treated as a holding brake. Orientation must be confirmed before accepting an operating envelope.

### Back EMF, voltage and missing dynamic calculations

For each phase, e_j = (dλ_j/dx)v. The relevant line voltage is e_A − e_B, etc. The generated results report the largest absolute saved phase and line gradient, which give voltage per m/s. Multiplying the projected force constant by velocity does not automatically give a phase-to-phase back-EMF value.

General phase voltage is v = Ri + d(Li)/dt + e_PM, with mutual terms in the inductance matrix and position dependence if present. A first current-ramp estimate is di/dt ≈ (V_available − Ri − e)/L only after defining the electrical circuit and inductance. The 12 mm adjacent-pair pitch implies a nominal 24 mm magnetic period, so f_e ≈ |velocity|/0.024 m away from end effects. Full force commutation should use a calibrated position/phase map.

Inductance matrix, bus voltage, maximum speed, PWM ripple, eddy losses, saturation, magnetic temperature effects, fatigue life, structural deflection and a thermal duty rating cannot be calculated numerically from the supplied evidence. Required inputs and tests are listed in the roadmap; no guessed values are presented as results.

---

## Bill of materials and procurement

This is a complete register of known parts and unresolved systems, not a fully orderable production BOM. Blank prices and supplier fields mean unknown, not zero. No total build cost can be stated until those items are selected. The machine-readable [BOM](../bom/bom.json) retains supplier, part-number and cost fields for future quotes.

| ID | Item | Quantity | Specification | Status |
|---|---|---:|---|---|
| MAG-01 | Axially magnetized disc magnet | 16 each | Ø10 × 5 mm; N42SH model label; coating and supplier properties pending | Geometry defined; material certificate needed |
| POL-01 | Steel pole ring | 7 each | Ø10 OD × Ø5 ID × 2 mm; steel grade/B-H curve pending | Geometry defined; alloy pending |
| TUB-01 | Carbon tube | 1 each | Ø12 OD × Ø10.2 ID × 94 mm; layup and tolerances pending | Nominal geometry defined |
| BOB-01 | Six-pocket bobbin | 1 each | Ø12.4 ID, Ø13.4 base OD, Ø16.8 lands, 45 mm length; material/process/routes pending | Provisional custom part |
| WND-01 | Wound coil | 6 each | 80 turns; 4 mm width; Ø13.4–16.8 mm envelope | Trial winding required |
| WIRE-01 | Enamelled copper wire | TBD m | 0.250 mm bare; Grade 1; ≤0.281 mm finished; see calculated procurement length | Trial purchase only; full-build quantity calculated |
| BOB-TRIAL | Single-pocket trial former | 1 each | Rev64 pocket dimensions; actual lead/crossover design required | Additional prototype tooling; CAD not supplied |
| ADH-01 | Adhesive / impregnation | TBD quantity TBD | Compatibility, cure and thickness to be selected | Open |
| RET-01 | Stack retention and assembly fixture | TBD set TBD | End retention, magnet forces and tolerances to be designed | Open |
| GUIDE-01 | Linear guidance and carriage | TBD set TBD | Travel/load/stiffness, attachment and alignment to be specified | Open |
| STOP-01 | Mechanical stops and limit system | TBD set TBD | Usable stroke and failure behaviour to be specified | Open |
| LEAD-01 | Lead harness and terminals | TBD set TBD | Flexible leads, strain relief, connectors and phase topology to be detailed | Open |
| ENC-01 | Position sensor and mount | TBD set TBD | Accuracy, resolution, interface and datum pending | Open |
| DRV-01 | Three-phase current controller | 1 set | Current convention, inductance, bus voltage and encoder compatibility pending | Selection open; no rated current established |
| PSU-01 | Power supply and electrical protection | 1 set | Bus voltage/current, energy handling and protection pending | Selection open |
| TEMP-01 | Temperature sensors | TBD quantity TBD | Sensor placement, range and electrical isolation pending | Open |
| TEST-01 | Test equipment | 1 set | Suitable micrometer, resistance instrument, calibrated load cell, current measurement and temperature logging | Equipment checklist; not motor mass |

WND-01 is the wound subassembly and WIRE-01 is its raw material: do not count both as purchased finished coils plus purchased winding wire unless intentionally outsourcing spares. The trial former is additional tooling, not part of the 31-solid assembly. The reference annulus is excluded from the BOM.

Use the generated calculations for wire consumption and the separate full-build-plus-trial purchase allowance. Obtain a small trial spool before a production order. Confirm magnet coating dimensions, actual tube tolerances and bobbin process before releasing custom parts.

---

## Winding and electrical connections

### First-coil wire specification

Request solid enamelled copper magnet wire with 0.250 mm nominal bare conductor, Grade 1 insulation and a supplier-guaranteed finished diameter ≤0.281 mm. Ask for the insulation chemistry, thermal class, resistance per metre, batch certificate and handling/termination guidance. Thermal class and enamel grade are different specifications. Final thermal class must be compatible with the selected bobbin, adhesive and temperature envelope.

The manufacturer's IEC table lists Grade 1 finished diameter 0.267–0.281 mm and nominal resistance 0.3482 Ω/m for 0.250 mm copper. [Elektrisola diameter/resistance table](https://www.elektrisola.com/Attachments/TechnicalDataBySize/ELEKTRISOLA_EnCuWire_IECJIS_Datasheet_eng.pdf).

Generic AWG30, Grade 2 or self-bonding wire must not be accepted by name alone. Additional coatings count toward finished diameter. A 20–25 m trial spool permits several winding attempts, but it is not the calculated procurement quantity for all six production coils plus a trial.

### Single-pocket trial

1. Identify the bobbin process/material and measure the actual bore, base diameter and pocket width. Design a smooth lead exit and crossover route before winding. The original CAD does not contain those routes.
2. Record wire supplier and lot. Check finished diameter at multiple positions using suitable low-force measurement. Keep the supplier's maximum specification as the procurement requirement.
3. Label start and finish leads. Define and photograph the winding direction from a stated viewing end; do not rely on an ambiguous clockwise instruction.
4. Trial the six-layer plan, counting 14, 14, 13, 13, 13, 13 turns from inner to outer layers. Record actual build after each layer. Use supplier-compatible tension and avoid damaging enamel at flange edges.
5. Record final OD, width, turn count and resistance at a measured temperature. Compare against the calculation with actual lead length.
6. Inspect insulation integrity and lead strain relief before impregnation. Select an insulation test method/voltage compatible with the actual insulation system and equipment; none is prescribed by the recovered design.
7. Confirm fit after the intended impregnation/cure process. Use the trial record to release or redesign the pocket. Do not force an oversized winding into the envelope.

### Phase mapping

| Coil | Centre at zero, mm | Phase | Proposed pair |
|---|---:|---|---|
| C1 | −20 | A | C1 + C4 in series |
| C2 | −12 | B | C2 + C5 in series |
| C3 | −4 | C | C3 + C6 in series |
| C4 | 4 | A | C1 + C4 in series |
| C5 | 12 | B | C2 + C5 in series |
| C6 | 20 | C | C3 + C6 in series |

Each FEMM label has +80 turns. A matched physical winding direction and additive series connection must reproduce that sign convention. Confirm induced-voltage polarity or restrained low-current force direction before making final series joints. A model's positive turns do not identify physical start/finish terminals by themselves.

```mermaid
flowchart LR
  A[Phase A terminal] --> C1[Coil 1] --> C4[Coil 4] --> N[Candidate star point]
  B[Phase B terminal] --> C2[Coil 2] --> C5[Coil 5] --> N
  C[Phase C terminal] --> C3[Coil 3] --> C6[Coil 6] --> N
```

This is a proposed star topology for planning, not a recovered terminal drawing. Controller compatibility, neutral treatment and verified series polarity are required before wiring release. Keep individual coil leads accessible during the trial stage. All current and resistance calculations state their topology explicitly.

---

## Mechanical assembly and tolerances

### Nominal geometry is not a shop drawing

The CAD includes five full-width 4 mm separator lands and two 0.5 mm end flanges. These were provisional additions in Rev62 and remain provisional in Rev64. Bobbin material candidates PEEK or G10 appear in the old workbook; neither is a selected, qualified process for this geometry.

Define manufacturing tolerances on the actual drawing before ordering final custom parts. In particular, Ø12.4 bore and Ø12 tube give only 0.20 mm nominal radial clearance. Tube straightness, ovality, bobbin shrinkage, guidance alignment and temperature expansion all contribute to minimum running clearance.

For measured worst-case diameters, radial clearance c_min = (bobbin_ID_min − tube_OD_max)/2 − eccentricity_allowance. Similar stack-to-tube clearance is (tube_ID_min − magnet_OD_max)/2 before coating and assembly allowances. A numerical tolerance budget requires those actual limits.

The nominal winding OD allowance relative to the reference bore is only (17 − 16.8)/2 = 0.10 mm, but no physical reference housing is selected. Do not use this as a verified bearing fit.

### Assembly sequence to develop

1. Inspect magnet dimensions, axial magnetization and pole-ring geometry. Confirm pole material and magnet supplier certificate. Use a suitable fixture for the interacting magnets; the alternating stack contains repelling interfaces and needs defined retention.
2. Define adhesive gaps and end retention, then calculate the assembled stack length and revise CAD/FEMM if the nominal 94 mm changes.
3. Trial the fixed stack inside the measured carbon tube without damaging coatings. Do not treat the Ø5 pole-ring holes as a continuous bore through the solid magnets.
4. Complete the single-pocket winding trial and winding inspection before committing to the six-pocket former.
5. Add coil crossover routes, lead exits and strain relief while preserving the required radial envelope. Record any geometry change as a new revision.
6. Design carriage attachment, guides, end stops and encoder datum together. The winding pack must not carry unspecified lateral loads through rubbing contact with the tube.
7. Confirm free travel and measured margins with the assembled lead harness before electrical commissioning.

This is a development sequence. Detailed retention, guidance and connection drawings remain required for assembly release.

### Material and environment requirements

Record bobbin modulus, creep behaviour and temperature limit; adhesive cure shrinkage and temperature range; tube thermal expansion, straightness and conductivity; magnet temperature-dependent properties and coating. The minimum compatible limit of the insulation/material system constrains operation. Carbon composite properties depend on layup, so a generic isotropic assumption does not establish thermal or mechanical performance.

Mass, stiffness, buckling, bearing life and fatigue calculations are pending the carriage, support spans, material properties, load directions and duty cycle. Do not substitute the 0.5 kg historical carriage target for a measured moving assembly mass.

---

## Simulation and reproduction

### Archived model

The preserved Rev64 FEMM file is a static axisymmetric model in millimetres with precision 1e−8, a zero-vector-potential outer boundary and an approximately r = 0–30 mm, z = −60–60 mm air domain. All six coils are group 100. Their radii are 6.7–8.4 mm and their centres are −20, −12, −4, 4, 12, 20 mm. The saved starting phase currents are −1, +0.5, +0.5 A; the sweep resets them to zero.

| Material | Saved model assumption |
|---|---|
| Air and implicit bobbin | Relative permeability 1 |
| CarbonTube | Relative permeability 1, conductivity 0 |
| Steel_firstpass | Constant relative permeability 1000, no B–H points |
| N42SH_firstpass | Relative permeability 1.05, coercive field 1,000,000 A/m |
| Copper | Conductivity 58 MS/m; no explicit individual-wire geometry |

The magnetic material label is not a verified supplier material curve. The model omits thermal feedback, real steel saturation, magnet temperature dependence, PWM and conductive carbon-tube losses. Treat winding resistance from physical wire geometry and measurements separately from a homogenized coil-region solution.

### What the archived sweep does

It translates the whole coil group through 161 positions at 0.25 mm increments over ±20 mm, extracts zero-current PM circuit flux linkages, differentiates them and calculates balanced optimum current vectors. It then solves positive and negative currents at −20, 0 and +20 mm and integrates axial Lorentz force on all six coil regions.

FEMM `mo_blockintegral(12)` is the steady-state axial Lorentz-force component for an axisymmetric magnetic model. The official [FEMM manual](https://www.femm.info/Archives/doc/manual.pdf) documents the integral and circuit-property APIs. The air-like coil permeability makes this force calculation appropriate for the coil regions.

The saved direct-force comparisons are within 0.35%; the largest even component is about 0.000059 N. Recalculation of saved data is not a new finite-element solve. Archived CAD-kernel reimport checks are also preserved evidence, not rerun by the documentation tools.

### Fresh runs without overwriting the archive

The preserved Lua uses absolute paths from its original computer location. Do not run it in place. Instead:

```sh
python tools/prepare_femm.py --output work/femm-trial-01
```

The tool creates a new directory, copies the centred model, adapts only the input/output paths in a copied Lua script, and removes automatic application exit. It refuses an existing output directory. Open FEMM and use its Lua script command to select the generated script. The script creates new CSVs inside the run directory. The original simulation directory stays untouched.

Do not apply the older −36 mm translation to this already-centred model. Wait for the run's `progress.txt` to report completion. Archive the new model, outputs, solver version and machine/run notes together. The run preparation tool has been checked for file isolation; the resulting Lua has not been executed as part of this documentation task.

### Before treating force as a release value

Perform mesh refinement and air-boundary sensitivity studies, compare central and endpoint differentiation schemes, add supplier magnetic curves and temperature cases, check proposed metal fixtures, measure force at known phase currents and positions, and resolve the actual drive's commutation law. Losses and dynamics require additional models and measurements. Model convergence at a numerical precision setting alone does not establish physical accuracy.

---

## Commissioning and measurement records

The recovered workbook contains no completed test evidence. Use the empty [Rev64 record templates](../records/README.md) for new measurements. Every measurement needs a build identifier, revision, date, instrument and calibration/reference information. Preserve raw readings separately from calculations.

### Stage 1: winding and mechanical fit

Record actual wire diameter, bobbin dimensions, layer count, turn count, final OD/width, lead length, resistance and measurement temperature. Inspect insulation and strain relief. Confirm the intended cure does not cause interference. Release the six-coil build only after the single-pocket trial passes a defined drawing and electrical inspection.

### Stage 2: phase and encoder verification

Confirm each series pair's polarity. Measure all coil resistances individually before joining, then each phase and line-to-line resistance under the selected topology. Record reference temperatures. Verify the encoder datum at magnetic centre and restrained motion direction. Initial ±18 mm soft limits are historical proposals; establish mechanical stops and verify usable travel before adopting them.

### Stage 3: static force

Use a restrained fixture and calibrated load cell. Record actual IA, IB, IC, position, F+ and F−, including force sign and zero offset. Obtain the current vector for the actual position from Rev64 data and state the scale. Compute F_pred = g·i, F_odd = (F+ − F−)/2 and F_even = (F+ + F−)/2. Use the same coordinate and force sign conventions throughout.

The saved file's IA_norm/IB_norm/IC_norm entries have unit vector magnitude, not unit phase peak. For equivalent phase-peak scale Ipk, multiply them by sqrt(3/2)Ipk. Recalculate the predicted target if current changes. Do not copy the old workbook's fixed Rev62 target numbers into a new run.

### Stage 4: thermal characterization

Select compatible material temperature limits and an initial restrained, current-limited test plan before applying power. The old workbook's current candidates and 120°C entry are not approved Rev64 settings. Record waveform, all relevant currents, ambient, elapsed time, duty, coil sensor temperatures, phase resistance, reference resistance/temperature, assembly state and stop reason.

Calculate copper loss from actual phase currents and temperature-corrected resistances. For unequal phase resistances, sum R_A i_A² + R_B i_B² + R_C i_C². Resistance thermometry estimates average winding temperature. A surface NTC and a resistance estimate can miss a local hot spot, so record both where available.

The old <1°C over 10 minutes criterion may be a useful proposed stability check, but dwell time and acceptable drift must be specified for the finished assembly. Establish thermal resistance only from stable readings with known mounting and ambient conditions. Current promotion needs measured evidence, not extrapolation from a short cold pulse.

### Release evidence

Before declaring continuous or peak ratings, close winding fit, all coil inspections, polarity, guidance, retention, limits, force mapping, thermal characterization and controller protection. Peak current needs an explicit duration, repetition/duty, starting temperature and cooling condition. Continuous force needs a defined ambient and mounting arrangement. Record unresolved deviations and do not label a pending item as passed.

---

## Open decisions and milestones

| ID | Decision / work | Required evidence | Status |
|---|---|---|---|
| M1 | Confirm axis orientation, moving mass, acceleration and stroke | Updated requirements including gravity, friction and cable forces | Open |
| M2 | Qualify wire and single-pocket winding | Supplier certificate and measured 80-turn sample after cure | Open |
| M3 | Detail bobbin and crossover channels | Material/process choice, tolerance drawing and lead routing | Open |
| M4 | Detail magnet retention and tube installation | Adhesive gaps, fixture, end retention and tolerance stack | Open |
| M5 | Design guidance, carriage, stops and sensor mount | Assembly CAD, loads, stiffness and measured free travel | Open |
| M6 | Confirm electrical topology and polarity | Terminal drawing, individual coil/phase resistance and polarity record | Open |
| M7 | Improve and validate electromagnetics | Material curves, mesh/boundary study and calibrated force measurements | Open |
| M8 | Select driver, encoder and power supply | Inductance/back-EMF data, required speed, current convention and interface | Open |
| M9 | Establish thermal and duty limits | Stable tests in final mounting and worst ambient | Open |
| M10 | Release prototype build | Closed deviations, complete BOM and approved manufacturing drawings | Open |

Recommended order: requirements confirmation and wire procurement in parallel, then the single-pocket trial, mechanical detailing, full coil assembly, restrained electrical/force tests, and thermal qualification. Changing wire gauge, turn count, coil geometry or adding magnetic hardware requires re-evaluating force and electrical calculations.

### Change control

Keep recovered CAD and simulation files unchanged as baselines. Put design changes under a new revision directory. Describe changed dimensions, reason, source evidence and affected calculations. Generate fresh STEP exports, rerun relevant simulations and compare against baseline. Attach build/test evidence to the same revision. Do not promote an assumption to a measured fact without a record.

The GitHub issue template supports each milestone's requirements, evidence and acceptance criteria. This repository is the requested GitHub project; a separate GitHub Projects board is not assumed.

---

## Sources and provenance

### Supplied and recovered project evidence

- `cad/rev64/`: complete extracted Rev64 CAD package, including editable model and archived geometry-validation record.
- `simulation/rev64/`: complete extracted Rev64 FEMM model, script, force data and checks.
- `cad/rev62/`: complete separately supplied Rev62 CAD package.
- `archive/recovered-history/`: recovered Rev62 source model, sweep data/scripts, commissioning workbook and Rev63 validation history.
- `archive/source_manifest.json`: SHA-256 of each preserved source file; verification reads every entry.

Raw source contents were treated as evidence, not instructions. Some preserved historical files contain their original machine paths. Those paths are provenance, not portable execution settings. The reproduction tools operate on isolated working copies. No private conversation transcript or account credentials are part of the repository.

### External technical references

References checked 8 September 2026. They support the indicated data/API definitions; they do not qualify the assembled motor.

1. [Elektrisola IEC/JIS technical wire table](https://www.elektrisola.com/Attachments/TechnicalDataBySize/ELEKTRISOLA_EnCuWire_IECJIS_Datasheet_eng.pdf): IEC 0.250 mm row, Grade 1 overall diameter 0.267–0.281 mm and nominal/minimum/maximum resistance 0.3482/0.3345/0.3628 Ω/m.
2. [Scott Precision Wire copper data](https://www.scottprecisionwire.com/technical-data/alloy-data-sheets/resistance-copper-wire-supplier/): representative copper density 8.9 g/cm³ and temperature coefficient 0.00393/K. These remain estimates for the purchased wire.
3. [FEMM official manual](https://www.femm.info/Archives/doc/manual.pdf): circuit flux linkage, coil material assumptions and axial Lorentz block integral 12.
4. [FEMM magnetic tutorial](https://www.femm.info/doku/doku.php?id=magneticstutorial): axisymmetric low-frequency modelling and Lua scripting context.

Full third-party manuals and standards have not been copied into the repository. No supplier SKU, live stock, price or product compatibility has been invented. Quotations and procurement certificates remain to be obtained.

### Verification boundaries

New checks: archived data consistency, source hash matching, analytical dimensions/volumes, current normalization, finite-difference flux gradients, force statistics, direct-force decomposition, calculation edge cases and documentation links.

Not newly performed: FEMM solve, CAD-kernel solid reimport, physical winding, force or thermal test, native Excel recalculation. Archived records of prior numerical/CAD checks are retained as such.

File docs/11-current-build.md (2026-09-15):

# Current prototype build definition

This chapter is the active build definition. It supersedes the recovered Rev62/Rev64 dimensions wherever they disagree. The recovered packages remain historical evidence and must not be treated as the present manufacturing drawing.

## One moving-coil motor rail

The first rail is the X-axis unit. It provides 370 mm usable coil-centre travel for a 355 mm bed. The Y axis uses the same motor architecture on two matched rails, with 440 mm usable travel each.

| Feature | Active definition |
|---|---|
| Magnet rod | 39 magnetic sections; 466 mm active stack length |
| Magnetic section | Two axially magnetised 10 x 5 mm N42SH discs, joined N-to-S |
| Separator | 38 low-carbon-steel spacers, 10 mm OD x 8 mm ID x 2 mm; adjacent sections face the same pole across each spacer |
| Magnetic pitch | 12 mm section-to-section centre pitch |
| Tube | Carbon fibre, 12 mm OD x 11 mm ID; buy 500 mm and trim only after the stack and end retention are proven |
| Coil pack | Nine independent air coils, 8 mm centres, 69 mm overall axial length |
| Coil | 13 mm bore, 5 mm axial width, 120 turns AWG25 enamelled copper |
| Wire | 0.455 mm bare / about 0.496 mm finished; about 7.5 m prepared per coil |
| Phase order | A-B-C-A-B-C-A-B-C; three series coils per phase |
| Resin | Easy Composites EL160, with the maker's specified post-cure |
| Controller | One channel of MKS XDrive 3.6 at 48 V; a braking resistor is required for regeneration |

The current N42SH grade is essential for the 70 C heated chamber. Standard N52 is normally limited to about 80 C and is not an acceptable final motor magnet without a temperature rating from its manufacturer. Every magnet on a rod must come from the same grade and supplier batch. The two Y rods must be matched as a pair.

## Preferred encoder

The preferred feedback system is the RLS RLC2HD linear incremental encoder with a separate RLS MS05 magnetic scale. It is deliberately mounted on the rail side of the machine, away from the tubular motor magnet rod.

| Item | Selected part / setting |
|---|---|
| Readhead | `RLC2HDAD20B00C00` |
| Interface | 5 V single-ended TTL A, B and Z incremental signals |
| Resolution | 10 um (`D20`, 200 interpolation factor) |
| Edge separation | 0.5 us / 2 MHz (`B`) |
| Connector | No connector (`00`); solder a light flexible harness |
| Reference | Periodic reference every 2 mm (`C`) |
| X scale | `MS05AM450B0000`, 450 mm long, plus `CF050045` cover foil |
| Y scales | Two 500 mm MS05 scales and matching 500 mm cover foils; confirm final part numbers in the RLS configurator |

At 10 um, one 12 mm magnetic pitch contains roughly 1,200 encoder position increments. That is ample for force commutation; choosing 1 um would create ten times more pulses with no practical force or print-accuracy benefit. The selected readhead is directly compatible with the 5 V A/B/Z header on an MKS XDrive 3.6 / ODrive v3.6-style controller: connect 5V, GND, A, B and Z one-for-one. No EIA-422 converter is needed.

RLS specifies -30 to +85 C operation and permits less than 1 mT external field at the scale/readhead. The readhead and scale must therefore sit outside the motor's stray field and should not be installed inside the 70 C heated volume. Verify field and temperature at the final mount before relying on the encoder.

## Heat and operating limit

The 70 C-chamber thermal screen predicts approximately 142.5 C winding temperature after 30 minutes for the original 0.792 W-per-coil repeated-motion case. This is too close to Class-F wire insulation (155 C). Until the physical thermal test is complete, use a conservative 120 C winding limit and the 0.55 W-per-coil continuous design case. Coil liquid cooling is an option, but any metallic heat spreader around the moving coils must be slotted to avoid eddy-current drag.

## Required verification before full build

1. Confirm magnet grade, axial magnetisation and Br range on the supplier certificate.
2. Trial-wind and impregnate one 120-turn coil; measure bore, OD, width and resistance.
3. Prove that the coil carrier moves freely on the 12 mm tube before winding all nine coils.
4. Build and clamp a short magnet-stack trial before assembling the full 466 mm rod.
5. Verify the RLS scale/readhead stays below 1 mT and 85 C in its final rail-side position.
6. Establish current, phase polarity, force map and thermal duty with restrained tests before fitting the printer.

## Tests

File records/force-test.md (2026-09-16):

# Static force record

Build ID: ___   Date: ___   Revision: Current nine-coil prototype
Load-cell calibration and zero: ___
Position datum/instrument: ___
Fixture and force sign convention: ___
Current measurement instruments: ___

| Run | Position mm | IA A | IB A | IC A | F+ N | F− N | Predicted N | PM odd N | Even N | Difference % |
|---|---|---|---|---|---|---|---|---|---|---|
| | | | | | | | | | | |

`F_PM_odd = (F+ − F−)/2`; `F_even = (F+ + F−)/2`. Enter a prediction only from a future corrected, documented model using the same geometry, current vector and datum. The archived Rev64 gradient must not be used. Record drift, fixture friction, current reversal timing and position repeatability.

Disposition and supporting raw data: Pending

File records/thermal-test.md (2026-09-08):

# Thermal test record

Build ID: ___   Date: ___   Revision: ___
Mounting/cooling configuration: ___
Waveform/current convention/duty: ___
Selected temperature limits and their material sources: ___
Reference phase resistance R_ref (Ω) and temperature T_ref (°C): ___
Sensor locations/instruments/calibration: ___

| Time min | Ambient °C | IA RMS A | IB RMS A | IC RMS A | RA Ω | RB Ω | RC Ω | Coil sensors °C | Copper loss W | Resistance temperature °C | Stop reason |
|---|---|---|---|---|---|---|---|---|---|---|---|
| | | | | | | | | | | | |

For a time interval, copper loss = RA IA_RMS² + RB IB_RMS² + RC IC_RMS² using resistances representative of that temperature. State the RMS averaging interval. Resistance temperature = 20 + {(R/R_ref)[1 + 0.00393(T_ref − 20)] − 1}/0.00393. Use the same phase and measurement path for R and R_ref. Average copper temperature does not establish hotspot temperature.

Steady-state criterion, observations and dwell: ___
Proposed continuous/peak limit, duration and conditions: Unreleased
Disposition and supporting raw data: Pending

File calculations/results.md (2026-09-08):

# Generated calculation results

Generated from explicit parameters and archived CSV data. Electrical estimates include the assumed 0.20 m extra wire per coil. Current examples are not operating ratings. Changing geometry does not resimulate the archived force constants.

| Quantity (units in name) | Value |
|---|---:|
| stack length mm | 94 |
| coil pack length mm | 44 |
| bobbin length mm | 45 |
| coil id mm | 13.4 |
| radial window mm | 1.7 |
| window area mm2 | 6.8 |
| coil end margin at full travel mm | 5 |
| bobbin end margin at full travel mm | 4.5 |
| magnet to tube radial gap mm | 0.1 |
| tube to bobbin radial gap mm | 0.2 |
| wire radial build mm | 1.686 |
| wire axial build mm | 3.934 |
| radial allowance mm | 0.014 |
| axial allowance mm | 0.066 |
| finished diameter geometric ceiling mm | 0.283333333 |
| bare copper area mm2 | 0.0490873852 |
| cross section copper fill fraction | 0.57749865 |
| winding wire length per coil m | 3.78446304 |
| wire length with allowance per coil m | 3.98446304 |
| six coil wire consumption m | 23.9067782 |
| six coil purchase with waste m | 28.6881339 |
| six coils plus trial purchase m | 33.4694895 |
| coil resistance20 ohm | 1.38739003 |
| coil resistance20 low ohm | 1.33280289 |
| coil resistance20 high ohm | 1.44556319 |
| phase resistance20 ohm | 2.77478006 |
| star line line resistance20 ohm | 5.54956012 |
| six coil copper mass including allowance g | 10.444339 |
| bobbin volume mm3 | 2605.38562 |
| single coil envelope volume mm3 | 322.578734 |
| Rev64 k vector mean N per A | 2.37572205 |
| Rev64 k vector min N per A | 2.35104849 |
| Rev64 k vector max N per A | 2.41217428 |
| Rev64 k phase peak equivalent mean N per A | 2.90965339 |
| Rev64 k phase peak equivalent min N per A | 2.87943458 |
| Rev62 k vector mean N per A | 2.48520218 |
| mean k change percent | -4.4052805 |
| kf peak to peak over mean percent | 2.57293523 |
| historical horizontal inertia force N | 2.593 |
| historical vertical upward force no friction N | 7.496325 |
| historical horizontal equivalent peak current A | 0.900524018 |
| historical vertical equivalent peak current A | 2.60340174 |
| historical vertical hold force N | 4.903325 |
| max absolute phase back emf V per m s | 2.15925941 |
| max absolute line back emf V per m s | 3.38217876 |

## Current examples — not approved limits

| Equivalent phase peak A | Vector A | Minimum archived force N | Copper loss at 20°C W | Phase RMS current density A/mm² |
|---:|---:|---:|---:|---:|
| 0.1 | 0.12247 | 0.28794 | 0.041622 | 1.4405 |
| 0.5 | 0.61237 | 1.4397 | 1.0405 | 7.2025 |
| 0.75 | 0.91856 | 2.1596 | 2.3412 | 10.804 |
| 1 | 1.2247 | 2.8794 | 4.1622 | 14.405 |
| 1.5 | 1.8371 | 4.3192 | 9.3649 | 21.608 |
| 2 | 2.4495 | 5.7589 | 16.649 | 28.81 |

Resistance and loss rise with temperature. Force uses a first-pass magnetic model with no temperature derating.

Archived force comparison

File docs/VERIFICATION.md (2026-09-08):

# Documentation verification

Completed on 8 September 2026 using the bundled Python runtime.

- All 43 preserved source files matched their source manifest hashes.
- The Rev62 parent and Rev64 derived FEMM files matched the fingerprints recorded in the source check.
- All 161 Rev64 data positions, finite-difference flux gradients, balanced current vectors and force constants were checked.
- All three archived direct-force decompositions and reported differences were checked.
- Analytical volumes matched all 31 CAD component records; nominal end margins matched the archived travel checks.
- Generated numerical results matched a fresh calculation from the input parameters.
- Authored local documentation links resolved.
- Nine unit tests passed, covering the nominal fit, excessive wire diameter, invalid turn counts, excessive travel, lead allowance effects, gravity, current/loss normalization and isolated FEMM run preparation.

These checks do not include a fresh FEMM solve, CAD-kernel reimport, Excel recalculation or physical testing. The geometry-validation JSON records prior CAD checks. The commissioning workbook records pending tests, not completed measurements.

Reproduce with the commands in the repository README. Recheck after changing inputs, calculations or source files.

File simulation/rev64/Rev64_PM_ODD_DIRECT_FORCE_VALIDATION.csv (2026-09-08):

relative_position_mm | IA_unit_A | IB_unit_A | IC_unit_A | F_plus_N | F_minus_N | F_PM_odd_N | F_even_N | Rev64_KF_unit_N | difference_N | difference_percent
-20.000000 | -0.436751304199 | -0.379065745621 | 0.81581704982 | 2.41266905723 | -2.41258307041 | 2.41262606382 | 4.29934094832e-005 | 2.4084560897 | 0.00416997411669 | 0.173138889039
0.000000 | 0.407530744638 | -0.816496160782 | 0.408965416144 | 2.3818124935 | -2.38176934633 | 2.38179091992 | 2.15735846092e-005 | 2.37362411738 | 0.00816680253862 | 0.344064693261
20.000000 | 0.81568523938 | -0.376327659855 | -0.439357579525 | 2.4112939299 | -2.41141179943 | 2.41135286466 | -5.89347635451e-005 | 2.40775893374 | 0.00359393092463 | 0.149264566077

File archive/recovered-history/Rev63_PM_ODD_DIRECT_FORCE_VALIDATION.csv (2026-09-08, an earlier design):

relative_position_mm | IA_unit_A | IB_unit_A | IC_unit_A | F_plus_N | F_minus_N | F_PM_odd_N | F_even_N | Rev62_KF_unit_N | difference_N | difference_percent
-20.000000 | -0.438708467231 | -0.37701072225 | 0.815719189481 | 2.52395408477 | -2.52384551935 | 2.52389980206 | 5.42827105077e-005 | 2.52593826279 | -0.00203846073431 | -0.0807011305202
0.000000 | 0.409511296592 | -0.816495277119 | 0.406983980527 | 2.4949503229 | -2.49496043944 | 2.49495538117 | -5.05827339281e-006 | 2.49104972207 | 0.00390565910043 | 0.156787681347
20.000000 | 0.815633332544 | -0.37530974189 | -0.440323590654 | 2.52319698163 | -2.52333888129 | 2.52326793146 | -7.09498258156e-005 | 2.52341068009 | -0.000142748630142 | -0.00565697178299

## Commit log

2026-09-08 Document Rev64 motor project and development status
2026-09-08 Add engineering manual, BOM, calculations and build guidance
2026-09-08 Add traceable bill of materials and procurement fields
2026-09-08 Preserve complete Revision 64 CAD baseline
    [Rev64_bobbin_provisional.step, Rev64_carbon_tube.step, Rev64_centered_assembly.step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]
2026-09-08 Add Revision 62 comparison CAD baseline
    [Rev62_bobbin_provisional.step, Rev62_carbon_tube.step, Rev62_centered_assembly.step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]
2026-09-08 Add Revision 64 FEMM simulation evidence
    [Rev64_CENTERED_COIL_PM_KF.csv, Rev64_PM_ODD_DIRECT_FORCE_VALIDATION.csv]
2026-09-08 Archive recovered Rev62 and Rev63 project history
    [Rev62_CENTERED_COIL_PM_KF.csv, Rev62_build_and_commissioning_log.xlsx, Rev63_PM_ODD_DIRECT_FORCE_VALIDATION.csv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]
2026-09-13 Add Elmer magnetic motion study
    Add the three-position axisymmetric Elmer magnetic-field study, rendered motion animation, and study notes for the 10 mm magnet concept.
2026-09-13 Link Elmer magnetic motion study from project overview
2026-09-15 Document current 9-coil prototype and encoder
    Add the RLS RLC2HD preferred encoder configuration, sourcing links, and a one-rail X-axis bill of materials.
2026-09-15 Add machine-readable one-rail BOM
    Add the X-axis 370 mm travel BOM with magnet, winding, scale, sensor and drive requirements.
2026-09-15 Link project overview to current prototype
    Make the current nine-coil build definition and one-rail BOM visible from the repository overview.
2026-09-15 Correct active prototype documentation
    Replace the misleading Rev64 entry point with the active nine-coil build, mark unsupported simulations as historical, and link the current BOM and winding recipe.
2026-09-15 Add current nine-coil layout schematic
    Publish a clearly labelled schematic and mark old motion visuals as withdrawn engineering evidence.
2026-09-15 Make active rail BOM the default
    Replace the obsolete Rev64 BOM entry point and preserve the prior list separately.
2026-09-16 Update current build records
    Replace six-coil templates and archived force-gradient references with current nine-coil records.
2026-09-16 Update active two-stepper winder plan
    Replace the obsolete servo and 80-turn overview with the active two-stepper winding approach.
2026-09-16 Set active coil winding parameters
    Set the current 120-turn AWG25 trial values and preserve the obsolete automatic recipe separately.
2026-09-16 Withdraw unsupported Elmer motion study
    State clearly that the exploratory Elmer files do not represent the active motor and cannot support engineering claims.
